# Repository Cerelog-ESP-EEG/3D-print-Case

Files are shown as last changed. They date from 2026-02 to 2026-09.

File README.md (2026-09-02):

# 3D-Printed Case

This repository contains the files and instructions for custom 3D-printed enclosures designed for the **Cerelog ESP-EEG V1, V2 and 16CH devices**.

| Folder | Device | Size | Notes |
| :--- | :--- | :--- | :--- |
| [`case for 16CH/`](case%20for%2016CH/) | 16-channel | 120.30 x 50.67 x 11.65 mm | Snap fit, no screws. Parametric. Floor openings for the two underside DIP switches. |
| [`case for v2/`](case%20for%20v2/) | V2 | 102.60 x 46.55 x 11.35 mm | Snap fit, no screws. Parametric. |
| [`case for v1/`](case%20for%20v1/) | V1 | 113.23 x 53.98 x 15.00 mm | Legacy, hand-modelled. |

The V2 and 16CH cases are generated from a parametric script rather than modelled by hand — change a constant, re-run, get new STLs. Each folder has its own `README.md`, and a `stl/PRINT.md` with everything you need at the printer.

## Preview for v2 and 16CH Cases Below

| V2 | 16CH |
| :---: | :---: |
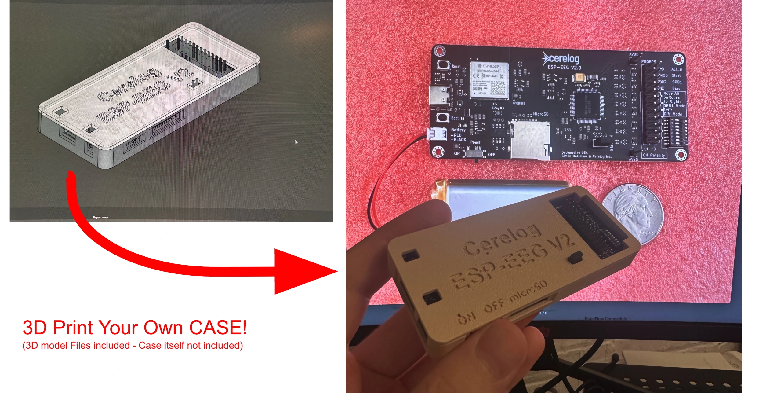
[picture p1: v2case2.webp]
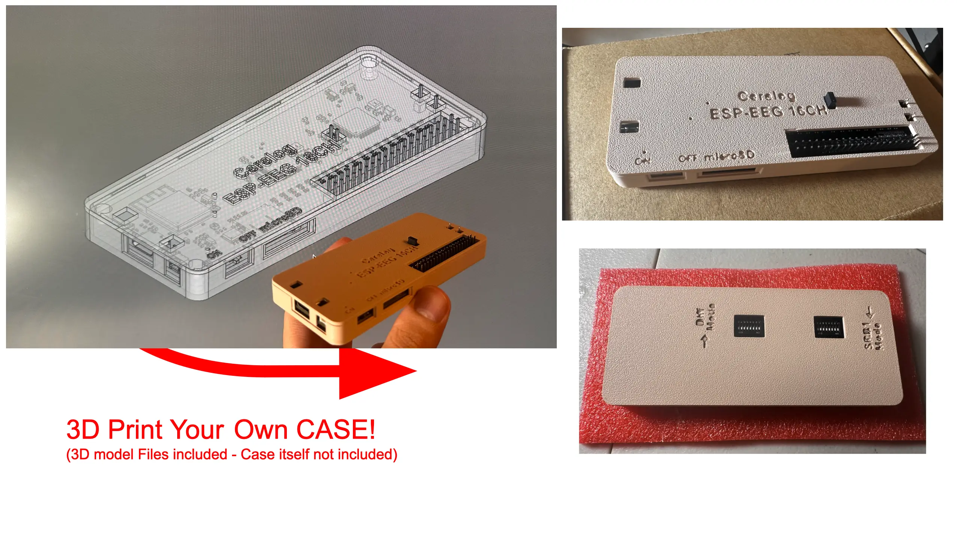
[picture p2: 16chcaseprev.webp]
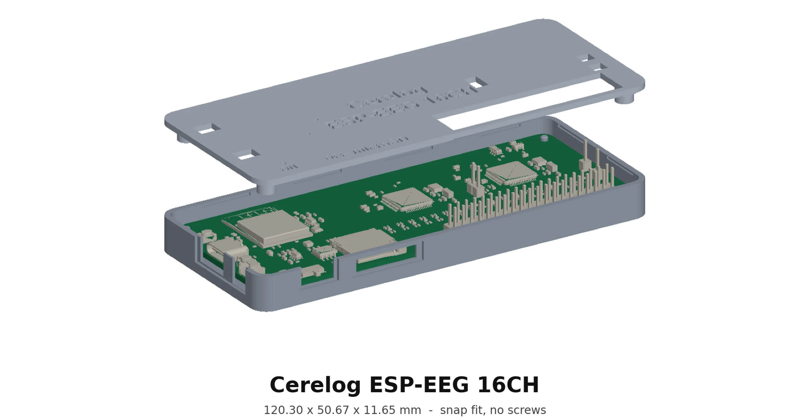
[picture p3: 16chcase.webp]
|  | <br><br> |
| 102.60 x 46.55 x 11.35 mm | 120.30 x 50.67 x 11.65 mm |

## Preview for v1 Case Below

| | | |
| :---: | :---: | :---: |
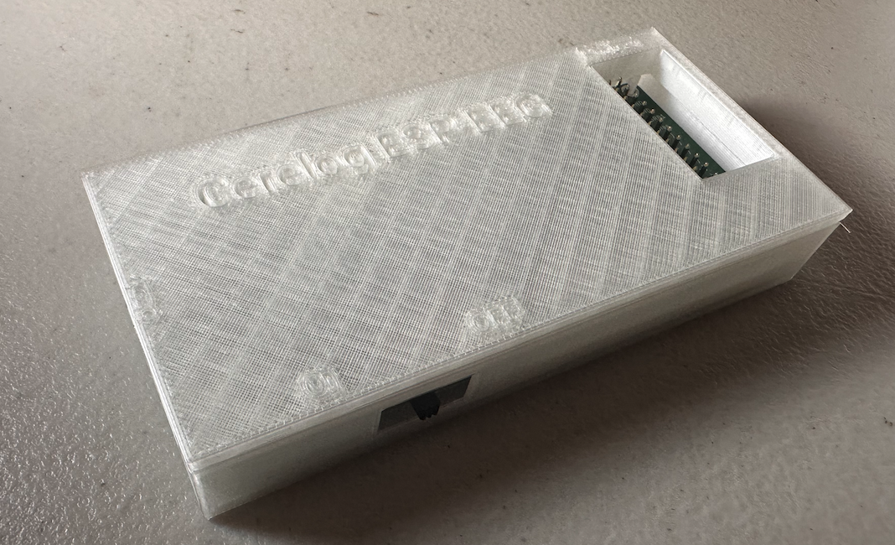
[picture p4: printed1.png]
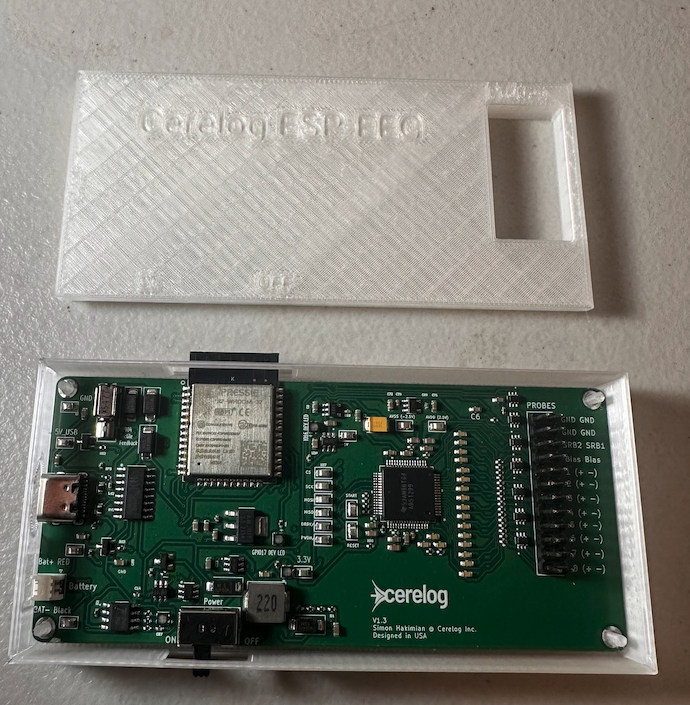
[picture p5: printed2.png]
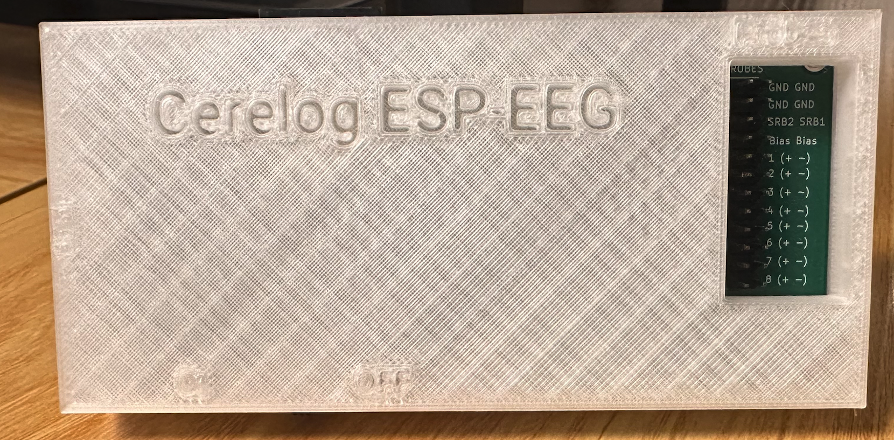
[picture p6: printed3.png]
|  |  |  |
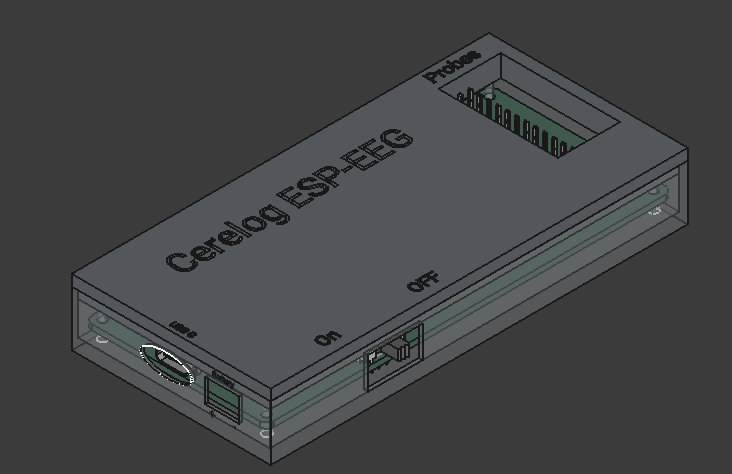
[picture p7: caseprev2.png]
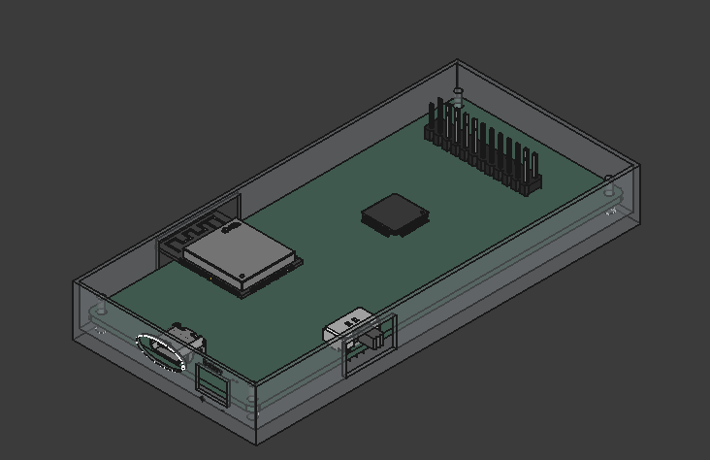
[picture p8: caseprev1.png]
|  |  | |

## Assembly Instructions

1. **Print Files:** Print the two **STL** files included in this repo. 
   > **Note:** The file `Optional_locking_base` is a legacy version with closed ends. You don't need to print it if you plan to tape the lid shut. While the normal lid closes, it can occasionally pop open; the legacy file is designed to prevent the PCB from sliding out.

2. **PCB Installation:**
   * Insert the **antenna** first.
   * Carefully bend the plastic near the **power button** and slot it in while **aligning** the holes with the **PCB**.

3. **Final Step:** Lastly, put the **cover** on.

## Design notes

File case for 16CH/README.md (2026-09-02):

# Cerelog ESP-EEG 16CH — 3D printed case

Snap-fit two-part enclosure, **120.30 x 50.67 x 11.65 mm**. No screws.

**Printing? Go straight to [`stl/PRINT.md`](stl/PRINT.md).**

## Folders

| Folder | What lives there |
|---|---|
| **`stl/`** | The two printable STLs and `PRINT.md`. This is all you need at the printer. |
| **`Case files FreeCAD/`** | FreeCAD documents — the case on its own, the case with the board in it, and the original KiCad STEP export. |
| **`design/`** | The parametric source, measurements, build log, previews, and `tools/`. |

## Seeing the whole assembly in FreeCAD

```sh
/Applications/FreeCAD.app/Contents/MacOS/FreeCAD "design/tools/show_assembly.py"
```

That opens `Case files FreeCAD/assembly_16ch.FCStd` — base, lid and all 220
real board solids in their true positions — with everything made visible, the
lid at 60% transparency and the base at 25% so you can see the fit. A document
built headlessly has no saved GUI state, so opening the file directly will show
most objects hidden; run it through that script the first time.

## How the design is built

The case is **not modelled by hand**. `design/case_16ch.py` builds both parts
from named constants and exports the STLs. Change a number, re-run, get new
parts.

```sh
FC=/Applications/FreeCAD.app/Contents/Resources/bin/freecadcmd
cd design && $FC case_16ch.py
cd tools  && $FC verify_fit.py      # must say PASS
```

`case_16ch.py` writes `design/case_16ch_params.json` on every build. Every tool
reads its dimensions from there, so nothing can drift out of sync with the
model.

## Current design

| | |
|---|---|
| Outer | 120.30 x 50.67 x 11.65 |
| Wall / floor / lid | 1.60 / 1.20 / 1.60 |
| Board mounting | 4 printed pegs, 3.00 mm shoulder, press fit, no screws |
| Lid retention | Snap fit — 9 bead/groove pairs on all four walls, 0.25 mm engagement |
| Lid location | 4 sleeves swallowing the pegs through the board |
| Base openings | USB-C, battery cable, slide switch, microSD, **2 DIP switch holes in the floor** |
| Lid openings | 2x20 electrode header, 1x02 header, 2x 1x01 pins, 2 buttons |
| Markings, lid | `Cerelog` / `ESP-EEG 16CH` engraved 0.80 mm; `ON` `OFF` `microSD` at 0.50 mm |
| Markings, base | DIP switch mode legend: `Diff Mode` (-X side) and `SRB1 Mode` (+X side), 3.40 mm text, rotated 90 deg so the arrows run along the DHA-08TQR travel axis. `Diff` points toward the connector edge, `SRB1` away. 0.50 mm deep, mirrored to read when the case is rolled over |
| LED holes | 3 x 1.20 mm through the lid |

Fit is verified by boolean intersection against all 220 real board solids from
the KiCad STEP — not by eye. Latest result is in `design/verify_fit.txt`.

## What changed from the V2 case

Three things drove the redesign; everything else is carried over.

1. **The electrode header moved to the -Y edge** and grew from 2x12 to 2x20.
   Its body stops 0.06 mm short of the lid rim's inner face, so the lid opening
   has to cut the rim away over 52 mm. Snap segments moved onto all four walls
   to compensate — V2 used the two long walls only.
2. **Two `DHA-08TQR` 8-position DIP switches are now on the underside** of the
   board, hanging 2.385 mm below it. They set the standoff height (`BOSS_H`
   3.00, up from V2's 2.50) and each gets a through-opening in the floor.
3. **The board grew** 98.80 x 42.75 -> 116.50 x 46.87.

Full comparison in [`design/16ch_measurements.md`](design/16ch_measurements.md).

## Open items

See [`design/OPEN_ITEMS.md`](design/OPEN_ITEMS.md). The short version: the DIP
switches are recessed 1.82 mm rather than proud (a hard conflict with header
pin clearance — read item 1 before printing a batch), **ON/OFF may be
reversed**, and the power switch actuator no longer reaches the outside face at
all, so it needs a slider cap.

## Not derivable from the files

Two 3D models in `16ch_step.step` are wrong and are deliberately ignored:
`530480210` (battery connector height) and the unnamed `SOLID` / `SOLID001` /
`SOLID002`. Both confirmed by the board designer on the V2 export; the same
models are present here. If either turns out to be real, case height and floor
need revisiting.

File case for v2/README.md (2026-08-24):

# Cerelog ESP-EEG V2 — 3D printed case

Snap-fit two-part enclosure, **102.60 x 46.55 x 11.35 mm**. No screws.

**Printing? Go straight to [`stl/PRINT.md`](stl/PRINT.md).**

## Folders

| Folder | What lives there |
|---|---|
| **`stl/`** | The two printable STLs and `PRINT.md`. This is all you need at the printer. |
| **`Case files FreeCAD/`** | FreeCAD documents — the case on its own, the case with the board in it, and the original KiCad STEP export. |
| **`design/`** | The parametric source, measurements, build log, previews, and `tools/`. |

## How the design is built

The case is **not modelled by hand**. `design/case_v2.py` builds both parts from
named constants and exports the STLs. Change a number, re-run, get new parts.

```sh
FC=/Applications/FreeCAD.app/Contents/Resources/bin/freecadcmd
cd design && $FC case_v2.py
cd tools  && $FC verify_fit.py      # must say PASS
```

`case_v2.py` writes `design/case_v2_params.json` on every build. Every tool
reads its dimensions from there, so nothing can drift out of sync with the
model.

## Current design

| | |
|---|---|
| Outer | 102.60 x 46.55 x 11.35 |
| Wall / floor / lid | 1.60 / 1.20 / 1.60 |
| Board mounting | 4 printed pegs, 2.50 mm shoulder, press fit, no screws |
| Lid retention | Snap fit — 6 bead/groove pairs, 0.25 mm engagement |
| Lid location | 4 sleeves swallowing the pegs through the board |
| Openings | USB-C, battery cable, slide switch, microSD; lid: header block, 1x02 header, 2 buttons |
| Markings | `Cerelog` / `ESP-EEG V2` engraved 0.80 mm; `ON` `OFF` `microSD` at 0.50 mm |
| LED holes | 3 x 1.20 mm through the lid |

Fit is verified by boolean intersection against all 156 real board solids from
the KiCad STEP — not by eye. Latest result is in `design/verify_fit.txt`.

## Open items

See [`design/OPEN_ITEMS.md`](design/OPEN_ITEMS.md). The short version: **ON/OFF
may be reversed** (no electrical data exists in a STEP file), two LED holes
land inside the engraved title, and the power switch still needs a slider cap
to be usable.

## Not derivable from the files

Two 3D models in `v2_step.step` are wrong and are deliberately ignored:
`530480210` (battery connector height) and the unnamed `SOLID` / `SOLID001` /
`SOLID002`. Both confirmed by the board designer. If either turns out to be
real, case height and floor need revisiting.

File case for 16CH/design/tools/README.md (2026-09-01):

# tools/

Verification and preview scripts for the 16CH case. None of these change the
design — `../case_16ch.py` is the only file that does.

They all read dimensions from `../case_16ch_params.json`, which `case_16ch.py`
rewrites on every build. Nothing hard-codes a Z value.

## The loop

```sh
FC=/Applications/FreeCAD.app/Contents/Resources/bin/freecadcmd

cd ../ && $FC case_16ch.py         # 1. build   -> stl/, Case files FreeCAD/, params
cd tools/
$FC verify_fit.py                 # 2. check   -> ../verify_fit.txt   MUST say PASS
$FC export_board_mesh.py          # 3. meshes for the renderer
python3 render_preview.py         # 4. picture -> ../preview.png
$FC build_assembly.py             # 5. case + board document
/Applications/FreeCAD.app/Contents/MacOS/FreeCAD show_assembly.py   # 6. open it
```

`measure_board.py` is run-once tooling: it produced
`../16ch_raw_measurements.txt`, which `../16ch_measurements.md` is written
from. Re-run it if the board is re-exported.

## What each does

| Script | Runs under | Purpose |
|---|---|---|
| `measure_board.py` | freecadcmd | Extracts board outline, mount holes, every solid's extents, below-board protrusions and edge-proximate parts. |
| `verify_fit.py` | freecadcmd | Every board solid vs base and lid, plus base-vs-lid, peg/sleeve mate, LED holes, DIP switch floor access and port alignment. Writes `../verify_fit.txt`. |
| `export_board_mesh.py` | freecadcmd | Tessellates the board for the renderer. Coarse; pictures only. |
| `render_preview.py` | python3 | Six-view z-buffer render to `../preview.png`. |
| `build_assembly.py` | freecadcmd | Rebuilds `assembly_16ch.FCStd` (case + board). |
| `show_assembly.py` | FreeCAD GUI | Opens it with everything visible, lid translucent. |
| `_paths.py` | — | Shared paths, params loader, bad-model list. |

## Four mistakes baked in as guardrails

**`verify_fit.py` uses a 0.001 mm3 threshold.** On the V2 case it was 0.5, and
that hid a real 0.09 mm3 collision — the check reported a clean fit that was
not clean. Do not raise it.

**`render_preview.py` uses a z-buffer, not depth sorting.** The painter's
algorithm version drew engraved text through the solid lid, which read as the
engraving cutting clean through when it was 0.80 mm into 1.60 mm. Do not
"simplify" it back to sorting triangles.

**`verify_fit.py` also checks port *alignment*, not just interference.** A
no-collision result only proves nothing touches; it does not prove an opening
is actually in front of a connector. The port check sweeps each connector's own
footprint outward through its wall and looks for material in the way.

**`verify_fit.py` measures whether the engraving perforates the lid.** On V2 a
bad preview render made the 0.80 mm engraving look like a through-cut and there
was no measurement to settle it. The check now boxes the lid from the plate
underside up to each engraving floor and reports the void volume — it must be
0.0000 mm3.

## Known-bad models in 16ch_step.step

Confirmed wrong by the board designer on the V2 export; the same models appear
here. Skipped by every check:

- `530480210` — battery connector, height wrong.
- `SOLID`, `SOLID001`, `SOLID002` — unnamed, claim 4.21 mm below the board.

They live in `_paths.BAD_MODELS_*`. If either turns out to be real, the case
height and floor both need revisiting.

`_paths.TOP_LEVEL` additionally drops the STEP's top-level compound
`"16chpcbcad 1"`, which repeats every child shape. Note the sub-parts
`"16chpcbcad 1.211"` ... `"1.216"` are **real** bottom-side solids and are kept.

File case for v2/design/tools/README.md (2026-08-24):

# tools/

Verification and preview scripts for the v2 case. None of these change the
design — `../case_v2.py` is the only file that does.

They all read dimensions from `../case_v2_params.json`, which `case_v2.py`
rewrites on every build. Nothing hard-codes a Z value.

## The loop

```sh
FC=/Applications/FreeCAD.app/Contents/Resources/bin/freecadcmd

cd ../ && $FC case_v2.py          # 1. build   -> stl/, Case files FreeCAD/, params
cd tools/
$FC verify_fit.py                 # 2. check   -> ../verify_fit.txt   MUST say PASS
$FC export_board_mesh.py          # 3. meshes for the renderer
python3 render_preview.py         # 4. picture -> ../preview.png
$FC build_assembly.py             # 5. case + board document
/Applications/FreeCAD.app/Contents/MacOS/FreeCAD show_assembly.py   # 6. open it
```

## What each does

| Script | Runs under | Purpose |
|---|---|---|
| `verify_fit.py` | freecadcmd | Every board solid vs base and lid, plus base-vs-lid, peg/sleeve mate, LED holes. Writes `../verify_fit.txt`. |
| `export_board_mesh.py` | freecadcmd | Tessellates the board for the renderer. Coarse; pictures only. |
| `render_preview.py` | python3 | Six-view z-buffer render to `../preview.png`. |
| `build_assembly.py` | freecadcmd | Rebuilds `assembly_v2.FCStd` (case + board). |
| `show_assembly.py` | FreeCAD GUI | Opens it with everything visible, lid translucent. |
| `_paths.py` | — | Shared paths, params loader, bad-model list. |

## Two mistakes baked in as guardrails

**`verify_fit.py` uses a 0.001 mm3 threshold.** It was 0.5, and that hid a real
0.09 mm3 collision — the check reported a clean fit that was not clean. Do not
raise it.

**`render_preview.py` uses a z-buffer, not depth sorting.** The painter's
algorithm version drew engraved text through the solid lid, which read as the
engraving cutting clean through when it was 0.80 mm into 1.60 mm. Do not
"simplify" it back to sorting triangles.

## Known-bad models in v2_step.step

Confirmed wrong by the board designer, skipped by every check:

- `530480210` — battery connector, height wrong.
- `SOLID`, `SOLID001`, `SOLID002` — unnamed, claim 4.21 mm below the board.

They live in `_paths.BAD_MODELS_*`. If either turns out to be real, the case
height and floor both need revisiting.

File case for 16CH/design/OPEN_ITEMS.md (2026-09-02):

# Open items — 16CH case

Ordered by how much damage each does if ignored.

## 1. DIP switches are recessed 1.82 mm, not proud  — needs a decision

The two `DHA-08TQR` 8-position DIP switches are on the underside of the board
and each has a through-opening in the case floor (12.90 x 9.70 mm, 0.80 mm
clearance all round). They are reachable with a pen tip. They do **not** sit
flush with the outside of the case.

Measured: switch underside sits at case Z **1.82**; the outside of the floor
is Z 0.00.

This is a hard geometric conflict, not an oversight:

```
switch underside   = FLOOR_T + BOSS_H - 2.385
flush with outside => FLOOR_T + BOSS_H = 2.385
with FLOOR_T 1.20  => BOSS_H = 1.185
but the header pins protrude 1.405  => they would hit the floor
```

Making the switches flush requires dropping `BOSS_H` from 3.00 to about 1.60
**and** adding relief pockets under every header pin row. That is the opposite
of "more clearance under the board", so it was not done.

**If you want them proud instead of recessed, say so** — it is `BOSS_H` plus a
`FLOOR_RELIEF` list, both already wired into `case_16ch.py`.

## 2. ON / OFF may be reversed — carried over from V2, still unresolved

`ON` is engraved at X -49.00, `OFF` at X -34.50, flanking the slide-switch
actuator at X -41.96. Those positions come from the actuator's location and
travel axis, which the STEP does give.

What the STEP does **not** give is anything electrical — no netlist, no
reference designators, no schematic. Nothing available here says which throw
of `MK-12C02-G020` actually powers the board.

**Action:** meter a real board, or check the schematic. Same open item as V2;
if it was resolved there, the answer carries over unchanged (same part, same
orientation).

## 3. Power switch still needs a slider cap

The actuator is a 1.30 x 1.16 mm nub. On this board it passes the board edge
by 0.36 mm:

```
actuator past board edge   0.36 mm
minus PCB-to-wall gap      0.30
minus wall (thinned to 0.60)
= it does not reach the outside face at all
```

Worse than V2, which had 1.00 mm of overhang. The 10.10 mm wall opening has
room for the travel, but you cannot work the switch with a fingertip. It needs
a third printed part: a socket that press-fits over the nub with a paddle
reaching out through the opening. **Not built.**

## 4. The -Y lid rim is interrupted over 52 mm

The 2x20 electrode header body stops **0.06 mm** short of the lid rim's inner
face, so the opening for it has to take the rim with it. Over X 0.30..52.30
the lid has no rim — just a 1.735 mm ledge of plate sitting on the 1.60 mm
base wall.

The opening is Y -23.60..-12.40, i.e. **11.20 mm** across a 5.08 mm header
body. It was widened 4.00 mm inboard on purpose, for finger room when seating
ribbon cables; the outer edge stayed at the wall.

Consequences, all accepted deliberately:

- No snap segments are possible on the -Y wall over that span. Retention there
  comes from the +Y wall (4 segments) and the two ends (3 segments). V2 used
  +/-Y only; this case uses all four walls.
- The lid is less stiff along that edge than V2's. If it bows in practice, the
  fix is a rib on the underside inboard of the opening, not a thicker lid.

## 5. Header pin clearance rests on a modelled value

`BOSS_H` 3.00 leaves 1.60 mm below the modelled header pin tips (-1.405) and
0.62 mm below the DIP switches (-2.385). Those are the *models'* values. Two
models in the V2 export already turned out wrong, and clipped through-hole
pins vary a lot with how they are trimmed.

**Action:** caliper a real assembled board before committing to a batch. The
DIP switch height in particular is worth checking — it is now the part that
sets the standoff.

## 6. Both STLs have self-intersecting facet pairs — benign, print them

`case_16ch_lid.stl` is **watertight, manifold, correctly oriented, and its
mesh volume matches the solid exactly** (9140.0 vs 9140.0 mm3) — but carries
24 self-intersecting facet pairs.

All of them sit between Z 10.90 and 11.65, i.e. inside the engraved lettering:
the `ON`/`OFF`/`microSD` label row and the title block. This is FreeCAD's
ShapeString glyph tessellation, not the case geometry — the same defect V2 had,
in the same strings. The count rose from 16 when the title was shrunk from
7.0 mm to 4.5 mm; smaller glyphs tessellate into more slivers. It is the same
benign class of defect either way.

No engraving perforates either part — `verify_fit.py` measures the void under
every engraved string and reports 0.0000 mm3 for all seven. Thinnest remaining
material is 0.80 mm under the lid title (of 1.60 mm) and 0.70 mm under the
bottom mode legend (of 1.20 mm).

**Do not run FreeCAD's mesh repair on it.** On V2 the sequence
`fixSelfIntersections` / `removeFoldsOnSurface` deleted real geometry and
broke solidity.

**Recommendation: print it.** Watertight + manifold + consistent normals is
what slicers actually need. If a slicer refuses, the one-line fallback is to
empty `LABELS` in `case_16ch.py` and rebuild.

`case_16ch_base.stl` carries **22** pairs, all in Z 0.00..0.50 — the band of
the bottom-face mode legend, i.e. the same glyph-tessellation defect. It was
completely clean before that legend was added, and the count dropped from 42
to 22 when the legend text went from 2.60 to 3.40 mm: bigger glyphs tessellate
into fewer slivers. Both parts are watertight, manifold, correctly oriented,
and match their solid volumes (base 11259.1 vs 11259.8, lid 9140.0 vs
9139.9 mm3).

## 7. Side-wall texture — not done, deliberately

Same reasoning as V2: use a **textured PEI build plate**. The lid prints
top-face-down so the bed texture lands on the visible face. Geometric texture
is additionally unsafe on the side walls here — they are locally thinned to
0.60-0.80 mm at the switch, microSD and -X ports.

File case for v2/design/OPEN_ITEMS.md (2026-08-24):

# Open items — v2 case

Ordered by how much damage each does if ignored.

## 1. ON / OFF may be reversed  — BLOCKING a production print

`ON` is engraved at X -38.00, `OFF` at X -27.00, flanking the slide-switch
actuator at X -32.46. Those positions come from the actuator's location and
its travel axis, both of which the STEP does give.

What the STEP does **not** give is anything electrical. There is no netlist, no
reference designator, no schematic. Nothing in any file available here says
which throw of `MK-12C02-G020` actually powers the board.

**Action:** meter a real board, or check the schematic. A case that labels the
power switch backwards is worse than one with no label at all.

## 2. Power switch is not usable — needs a slider cap

The actuator is a **1.30 x 1.16 mm nub** protruding 1.47 mm from the switch
body. It passes the board edge by only 1.00 mm.

```
actuator past board edge   1.00 mm
minus PCB-to-wall gap      0.30
minus wall (already thinned to 0.60)
= protrusion               0.10 mm
```

No wall thickness fixes this. Even at zero wall you would be sliding 0.70 mm of
a 1.3 mm-wide tab with a fingertip.

**Fix:** a third printed part — a socket that press-fits over the nub with a
paddle reaching out through the wall opening, widened to ~5 mm for a finger.
The existing 9.00 mm opening already has room for the travel. Not built yet.

## 3. Two LED holes pierce the engraved title  — cosmetic

| LED | Position | Lands in |
|---|---|---|
| `C2874118` | (-17.65, 2.53) | the `e` of `Cerelog` |
| `C2874116` | (-24.25, -4.07) | `ESP-EEG V2`, near `SP` |
| `C2874117` | (-39.60, -16.63) | clear |

The holes must stay over the LEDs, so the fix is to move the title. Shifting
the block to roughly Y +4.5 .. +20.5 clears both. Left alone because it is a
branding decision.

## 4. Header pin clearance rests on a modelled value

The 2.50 mm standoff leaves 1.09 mm below the modelled header pin tips
(-1.41 mm). That is the *model's* pin length. Two models on this board have
already turned out wrong, and clipped through-hole pins vary a lot with how
they are trimmed.

**Action:** caliper a real assembled board before committing to a batch.

## 5. Side-wall texture — not done, deliberately

A realistic moulded grain needs ~1800 shallow dimples. The boolean did not
complete in two minutes on a bare plate, and FDM cannot resolve a 0.18 mm
dimple anyway.

Use a **textured PEI build plate** instead. The lid prints top-face-down, so
the bed texture lands on the visible face and looks genuinely moulded.

Geometric texture on the side walls is additionally unsafe: they are locally
thinned to 0.60-0.80 mm at the switch, microSD and -X ports.

## 6. Lid STL has self-intersections in the engraved lettering

`case_v2_lid.stl` is **watertight, manifold, correctly oriented, correct
volume** — but carries 34 self-intersecting facet pairs.

All of them sit in the engraved letter walls, spanning 0.40 mm in Z (the
engraving depth). Isolated by testing each string on a bare plate:

| String | Self-intersects |
|---|---|
| `ON`, `OFF`, `Cerelog` | no |
| `microSD`, `ESP-EEG V2` | **yes** |

It is FreeCAD's ShapeString glyph tessellation, not the case geometry:

- Persists at every tessellation tolerance from 0.10 down to 0.01.
- Persists across Arial Bold, Arial, Arial Narrow Bold, Verdana Bold,
  Tahoma Bold and DIN Alternate — no font is clean for all three strings.
- Individual curved glyphs (`m c r o S D`) fail on their own at 3 mm; `i`
  does not. Larger sizes do not fix `microSD`.
- The underlying OCC solid is valid, with correct volume.

**Do not run FreeCAD's mesh repair on it.** The sequence
`fixSelfIntersections` / `removeFoldsOnSurface` drops the lid from
6501 mm3 to 2498 mm3 — it deletes real geometry and breaks solidity.

**Recommendation: print it.** Watertight + manifold + consistent normals are
what slicers actually need; self-intersections in engraved text are the most
common benign STL defect and are auto-repaired on import. If a slicer does
refuse, the one-line fallback is to empty `LABELS` and shorten the title.

`case_v2_base.stl` is completely clean on every check.

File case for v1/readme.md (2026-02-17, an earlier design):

## Assembly Instructions

Note; the file called Optional_locking_base is a legacy file with closed ends and requires the below instructions. You dont need to print it though if you are going to tape the lid shut. Normal lid closes but pops open sometimes and the legacy file can keep pcb from flying out.

1. **Print Files:** Print the two **STL** files included in this repo. 
2. **PCB Installation:** * Insert the **antenna** first.
    * Carefully bend the plastic near the **power button** and slot it in while **aligning** the holes with the **PCB**.
3. **Final Step:** Lastly, put the **cover** on.

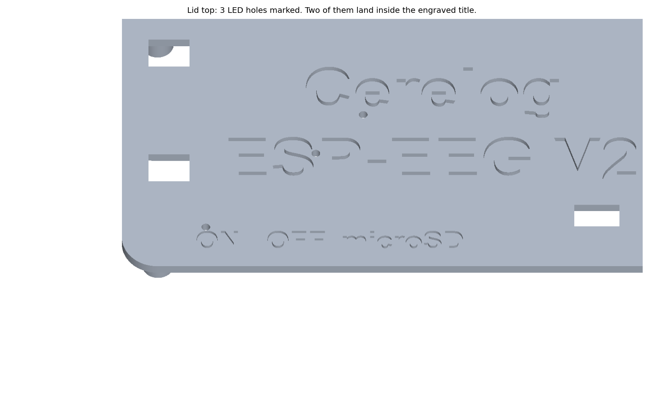
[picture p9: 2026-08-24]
case for v2/design/label_detail.png

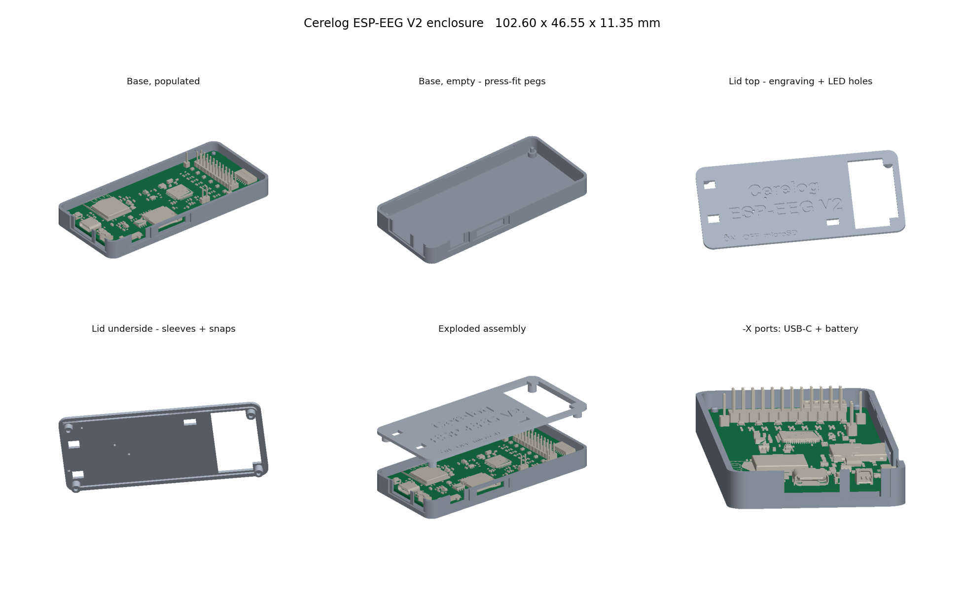
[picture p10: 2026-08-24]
case for v2/design/preview.png

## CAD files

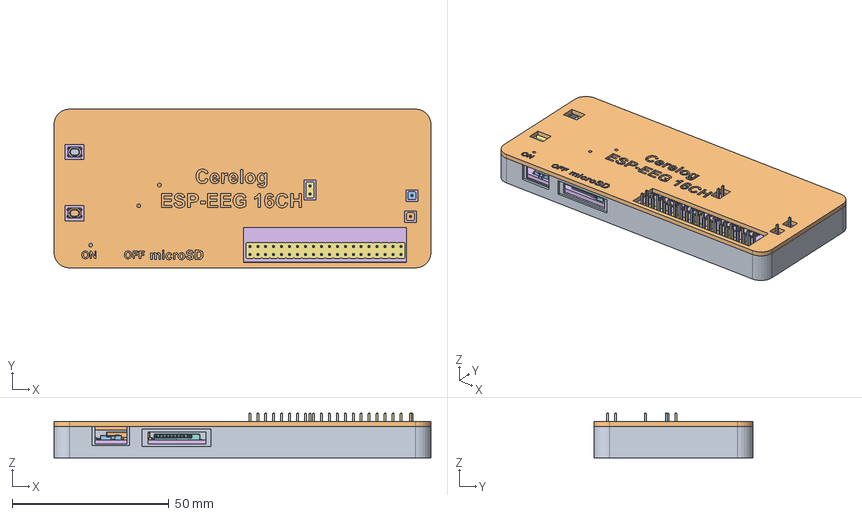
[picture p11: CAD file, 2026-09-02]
case for 16CH/Case files FreeCAD/assembly_16ch.FCStd
120.3 x 50.7 x 14.3 mm
CASE_BASE
CASE_LID
PCB: C_0603_1608Metric
PCB: C_0402_1005Metric
PCB: C_1206_3216Metric
PCB: R_0402_1005Metric
PCB: C_0402_1005Metric001
PCB: R_0402_1005Metric001
PCB: C_0402_1005Metric002
PCB: R_0402_1005Metric002
PCB: R_0402_1005Metric003
PCB: C_0402_1005Metric003
PCB: C_0402_1005Metric004
PCB: R_0402_1005Metric004
PCB: C_0402_1005Metric005
PCB: C_0402_1005Metric006
PCB: C_0402_1005Metric007
PCB: SKRPABE010
PCB: C_0603_1608Metric001
PCB: C_0402_1005Metric008
PCB: C_0402_1005Metric009
PCB: C_0402_1005Metric010
PCB: C_0603_1608Metric002
PCB: R_0402_1005Metric005
PCB: C_0603_1608Metric003
PCB: R_0402_1005Metric006
PCB: R_0402_1005Metric007
PCB: R_0402_1005Metric008
PCB: C_0402_1005Metric011
PCB: C_0402_1005Metric012
PCB: TAJB107K006RNJ
PCB: 530480210
PCB: C_0402_1005Metric013
PCB: R_0402_1005Metric009
PCB: C_0402_1005Metric014
PCB: R_0402_1005Metric010
PCB: C_0603_1608Metric004
PCB: C_0402_1005Metric015
PCB: R_0402_1005Metric011
PCB: C_0402_1005Metric016
PCB: TPS72325DBVR
PCB: C_0402_1005Metric017
PCB: C_0402_1005Metric018
PCB: C_0603_1608Metric005
PCB: C_0603_1608Metric006
PCB: C_0402_1005Metric019
PCB: R_0402_1005Metric012
PCB: TAJB107K006RNJ001
PCB: R_0402_1005Metric013
PCB: C_0402_1005Metric020
PCB: R_0402_1005Metric014
PCB: C_0402_1005Metric021
PCB: C_0402_1005Metric022
PCB: C_0603_1608Metric007
PCB: R_0402_1005Metric015
PCB: C_0402_1005Metric023
PCB: R_0402_1005Metric016
PCB: C_0402_1005Metric024
PCB: C_0603_1608Metric008
PCB: C_0402_1005Metric025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

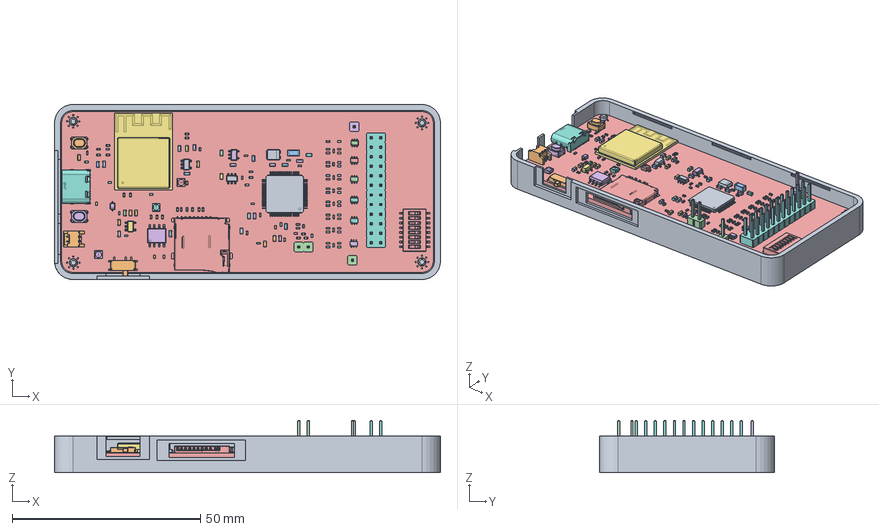
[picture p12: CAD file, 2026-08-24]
case for v2/Case files FreeCAD/assembly_v2.FCStd
102.6 x 46.6 x 13.8 mm
CASE_BASE
PCB: C_0603_1608Metric
PCB: C_1206_3216Metric
PCB: R_0402_1005Metric
PCB: C_0402_1005Metric
PCB: R_0402_1005Metric001
PCB: R_0402_1005Metric002
PCB: R_0402_1005Metric003
PCB: R_0402_1005Metric004
PCB: C_0402_1005Metric001
PCB: C_0402_1005Metric002
PCB: R_0402_1005Metric005
PCB: C_0402_1005Metric003
PCB: SKRPABE010
PCB: C_0603_1608Metric001
PCB: C_0402_1005Metric004
PCB: C_0402_1005Metric005
PCB: C_0402_1005Metric006
PCB: C_0603_1608Metric002
PCB: v2_step 1.19
PCB: R_0402_1005Metric006
PCB: R_0402_1005Metric007
PCB: R_0402_1005Metric008
PCB: C_0402_1005Metric007
PCB: TAJB107K006RNJ
PCB: 530480210
PCB: C_0402_1005Metric008
PCB: C_0402_1005Metric009
PCB: DHA-08TQR
PCB: TPS72325DBVR
PCB: C_0402_1005Metric010
PCB: C_0603_1608Metric003
PCB: C_0603_1608Metric004
PCB: R_0402_1005Metric009
PCB: C_0402_1005Metric011
PCB: C_0402_1005Metric012
PCB: C_0402_1005Metric013
PCB: C_0603_1608Metric005
PCB: R_0402_1005Metric010
PCB: C_0603_1608Metric006
PCB: C_0402_1005Metric014
PCB: C_0603_1608Metric007
PCB: R_0402_1005Metric011
PCB: C_0603_1608Metric008
PCB: C_0402_1005Metric015
PCB: C_0603_1608Metric009
PCB: C_0402_1005Metric016
PCB: C_0402_1005Metric017
PCB: R_0402_1005Metric012
PCB: R_0402_1005Metric013
PCB: C_0603_1608Metric010
PCB: PinHeader_1x01_P2.54mm_Vertical
PCB: R_0402_1005Metric014
PCB: C_0402_1005Metric018
PCB: C_0402_1005Metric019
PCB: PinHeader_2x12_P2.54mm_Vertical
PCB: R_0402_1005Metric015
PCB: C_0402_1005Metric020
PCB: C_0603_1608Metric011
PCB: C_0402_1005Metric021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

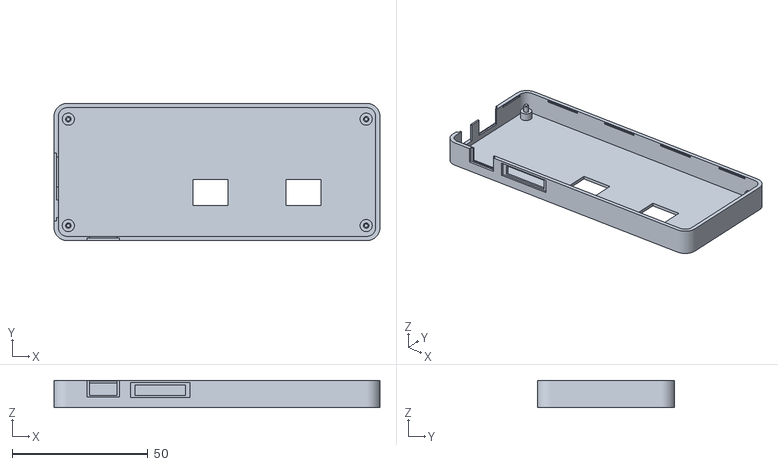
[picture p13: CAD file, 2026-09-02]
case for 16CH/stl/case_16ch_base.stl
120.3 x 50.7 x 10.1

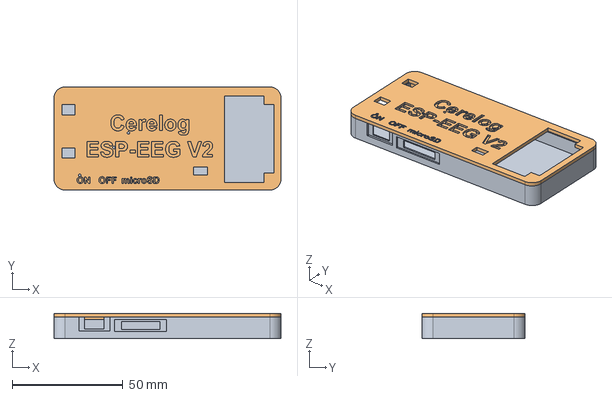
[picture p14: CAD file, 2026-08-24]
case for v2/Case files FreeCAD/case_v2.FCStd
102.6 x 46.6 x 11.3 mm
base
lid

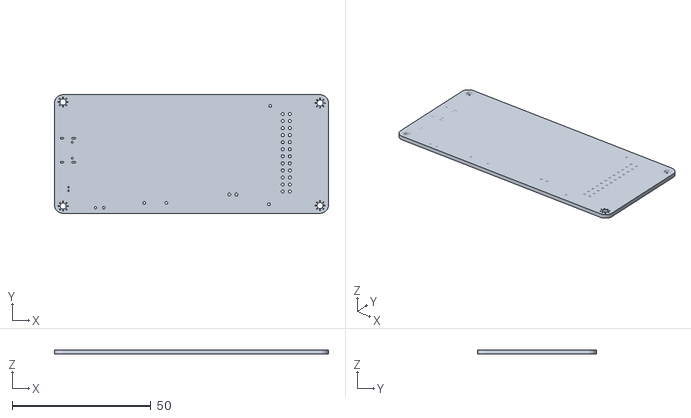
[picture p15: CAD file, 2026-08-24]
case for v2/design/tools/_pv_pcb.stl
98.8 x 42.8 x 1.51

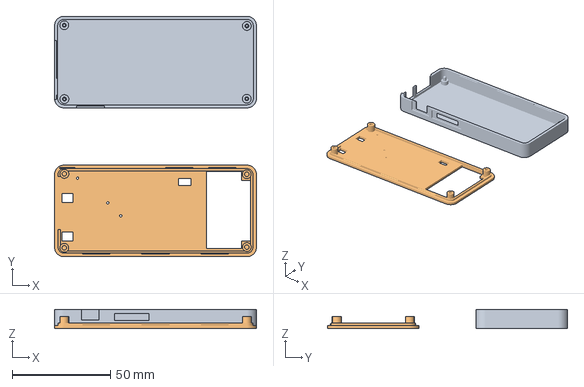
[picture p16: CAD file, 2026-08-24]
case for v2/stl/case_v2_base.3mf
102.6 x 122.1 x 9.75 mm
case_v2_base.stl
case_v2_lid.stl

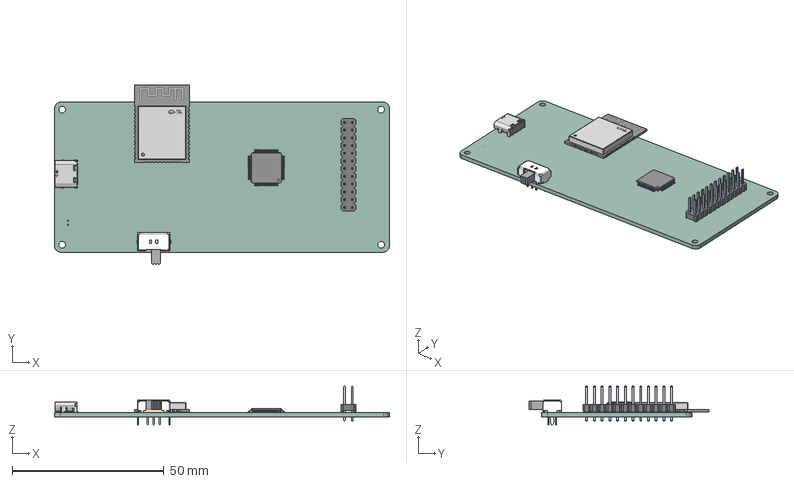
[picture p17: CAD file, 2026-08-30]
v2 FreeCad Design files/model_for_casedev.step
110.3 x 59.1 x 12.7 mm
PZ254V-12-24P
SK22D02L5
ADS1299-6PAG
ESP32-WROOM-32-N4
TYPE-C-16PIN-2MD-073
V6_EEG_1_3_Branch_PCB

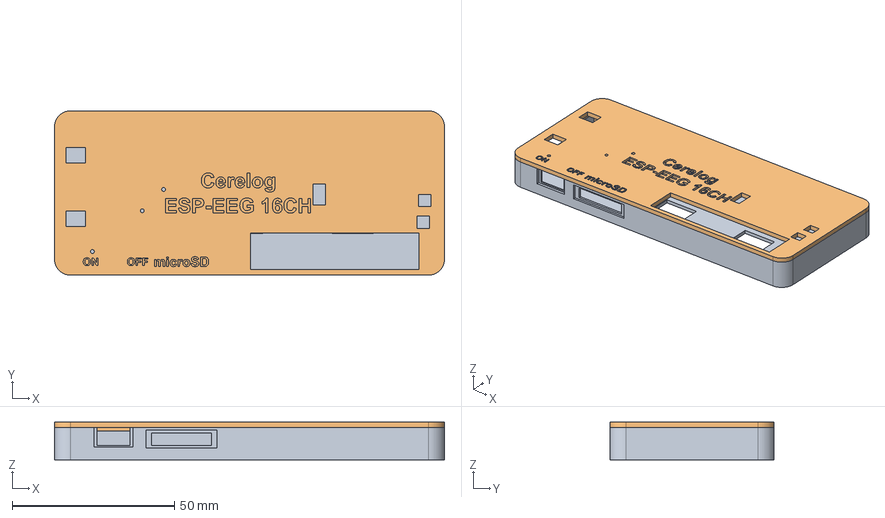
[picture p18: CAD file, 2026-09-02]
case for 16CH/Case files FreeCAD/case_16ch.FCStd
120.3 x 50.7 x 11.7 mm
base
lid

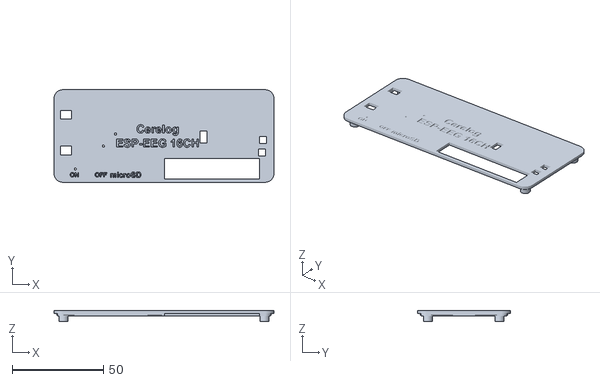
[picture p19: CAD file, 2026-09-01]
case for 16CH/stl/case_16ch_lid.stl
120.3 x 50.7 x 5.84

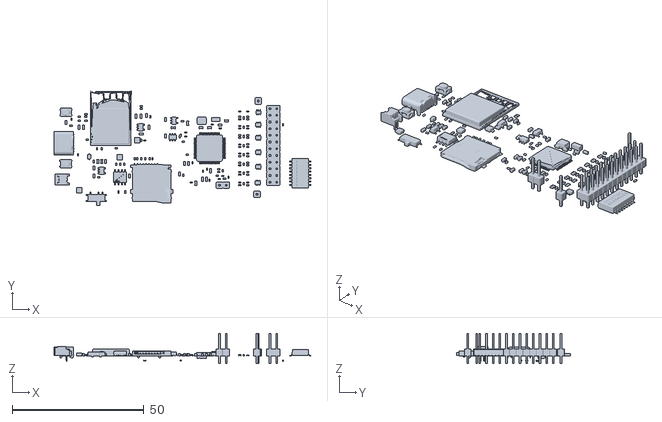
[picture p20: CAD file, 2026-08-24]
case for v2/design/tools/_pv_comp.stl
97.7 x 43.3 x 11.5

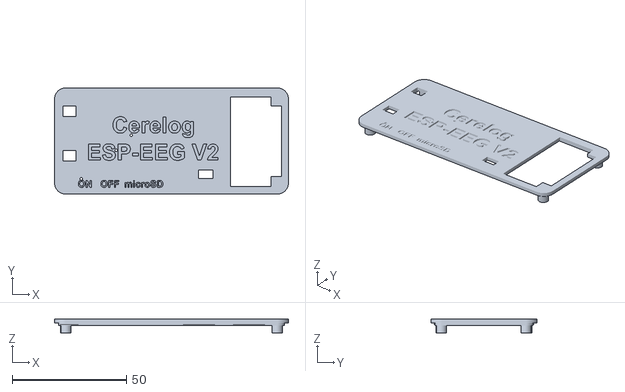
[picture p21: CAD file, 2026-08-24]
case for v2/stl/case_v2_lid.stl
102.6 x 46.5 x 6.04

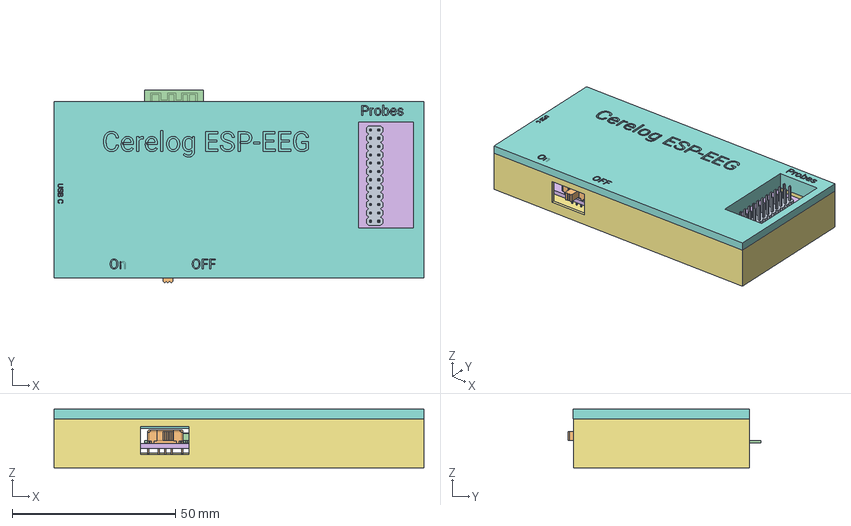
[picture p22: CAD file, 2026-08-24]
v2 FreeCad Design files/Case.FCStd
113.3 x 59.1 x 18.0 mm
PZ254V-12-24P
SK22D02L5
ADS1299-6PAG
ESP32-WROOM-32-N4
TYPE-C-16PIN-2MD-073
V6_EEG_1_3_Branch_PCB
Lid

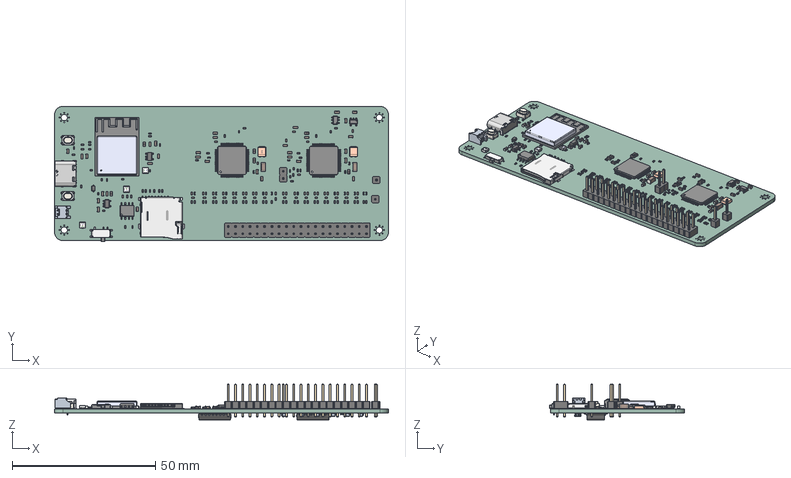
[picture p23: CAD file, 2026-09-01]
case for 16CH/Case files FreeCAD/16ch_step.step
116.5 x 47.2 x 12.5 mm
C_0603_1608Metric x 38
C_0402_1005Metric x 74
C_1206_3216Metric x 2
R_0402_1005Metric x 73
SKRPABE010 x 2
TAJB107K006RNJ x 2
TPS72325DBVR
PinHeader_1x01_P2.54mm_Vertical x 2
SOT-23-5 x 2
D_SOD-323
PinHeader_2x20_P2.54mm_Vertical
C2874116 x 3
ADS1299-6PAG x 2
ESP32-S3-MINI-1-N8
PinHeader_1x02_P2.54mm_Vertical
TF-SMD_TF-01A
TYPE-C-16PIN-2MD-073
TP4056-42-ESOP8
LM2664M6
16chpcbcad 1.211 x 6
DHA-08TQR x 2
V16CH_PCB

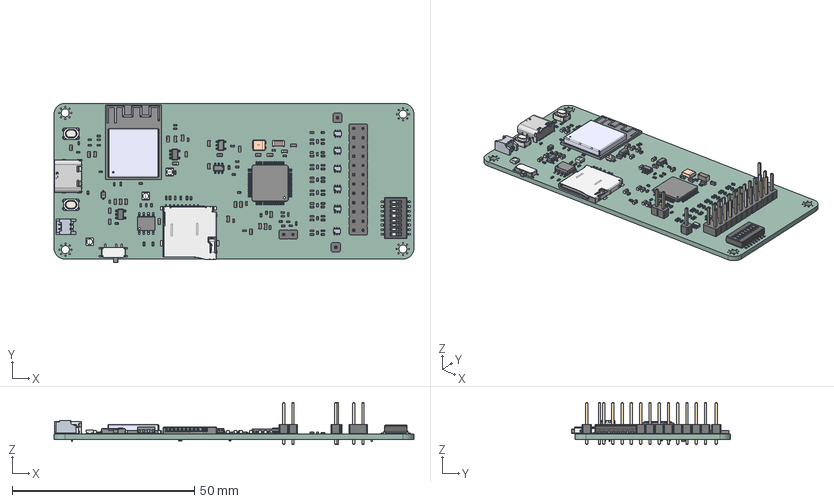
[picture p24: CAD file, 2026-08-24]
case for v2/Case files FreeCAD/v2_step.step
98.8 x 43.7 x 11.5 mm
C_0603_1608Metric x 29
C_1206_3216Metric
R_0402_1005Metric x 53
C_0402_1005Metric x 43
SKRPABE010 x 2
v2_step 1.19 x 6
TAJB107K006RNJ
DHA-08TQR
TPS72325DBVR
PinHeader_1x01_P2.54mm_Vertical x 2
PinHeader_2x12_P2.54mm_Vertical
SOT-23-5 x 2
D_SOD-323
C2874116 x 3
ADS1299-6PAG
ESP32-S3-MINI-1-N8
PinHeader_1x02_P2.54mm_Vertical
TF-SMD_TF-01A
TYPE-C-16PIN-2MD-073
TP4056-42-ESOP8
LM2664M6
2_0_PCB

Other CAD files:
v2 FreeCad Design files/better_base.FCStd
case for v1/case_base_fixed.stl
case for v1/case_lid.stl
case for v1/Optional_locking_base.stl
case for v2/stl/case_v2_base.stl

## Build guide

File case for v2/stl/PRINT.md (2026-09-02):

# What to print — Cerelog ESP-EEG V2 case

## Print these two. Nothing else.

Files here: https://github.com/Cerelog-ESP-EEG/3D-print-Case/tree/main/case%20for%20v2/stl

| File | What it is |
|---|---|
| `case_v2_base.stl` | Bottom half. Walls, floor, 4 press-fit pegs, all port openings. |
| `case_v2_lid.stl`  | Top half. Engraving, LED holes, snap beads, 4 sleeves. |

Assembled size **102.60 x 46.55 x 11.35 mm**. No screws, no hardware.

## Orientation — read this before slicing

**Base:** floor flat on the bed, walls up. This is how it exports. No supports.

**Lid: FLIP IT 180 degrees.** The STL exports with the rim and sleeves pointing
*down* (STL spans Z 5.31..11.35). If you drop it straight onto the bed the
slicer balances it on four sleeves and prints the plate in mid-air.

Rotate 180 degrees about X so the **engraved top face lies on the bed** and the
rim and sleeves build upward. Then there are no overhangs anywhere and no
supports are needed.

Bonus: a **textured PEI sheet** puts a moulded-grain finish on the lid top,
which is the face you look at. That is the intended finish — the texture is
deliberately not in the geometry.

## Settings

- Nozzle 0.4, layer 0.2. Nothing here needs finer.
- **No supports on either part.**
- Walls are 1.60 mm (4 perimeters). Locally 0.60-0.80 mm at the switch,
  microSD and -X ports — do not let the slicer gap-fill those away.
- Two bridges in the base, over the microSD opening (17.4 mm) and the switch
  opening (9.0 mm). Slow that layer down.
- 3-4 perimeters, 20-30% infill. Material is not critical; PETG or ABS if the
  snap needs to survive repeated opening, PLA is fine otherwise.

## Assembly

1. Drop the PCB straight down onto the four pegs in the base. It seats on the
   2.50 mm shoulders; the pegs pass through the 2.20 mm mounting holes.
   **No flexing or bending is needed** — unlike the v1 case. The slide switch
   overhangs the board edge by 0.695 mm, so its slot is cut open all the way
   to the top of the wall to let the board drop in vertically. Verified by
   sweeping every protruding part down its insertion path against the base.
2. Press the lid on. The four sleeves swallow the protruding pegs, and three
   snap beads per long wall click into grooves in the base wall.
3. To open: pull from a short end. The snaps are 0.25 mm engagement, split
   into 14 mm segments so they release without tools.

## Before you print a second one

Three things are unresolved and would change the parts:

- **ON / OFF may be backwards.** The labels are placed from the switch
  actuator's position and travel axis. The STEP carries no electrical data, so
  nothing told me which throw actually powers the board. Meter it.
- **Two LED holes pierce the engraved title** (in `Cerelog` and `ESP-EEG V2`).
  Works fine, looks like damage. Fix is to move the title, not the holes.
- **The power switch actuator is a 1.30 x 1.16 mm nub** and sits roughly flush
  with the wall. No wall thickness fixes this; it needs a printed slider cap,
  which does not exist yet.

## Known-bad data in v2_step.step

Two 3D models in the KiCad export are wrong and were deliberately ignored:

- `530480210` battery connector — height is wrong.
- `SOLID`, `SOLID001`, `SOLID002` — unnamed, claim to hang 4.21 mm below the
  board. Confirmed not real.

If either turns out to be genuine, the case height and floor need revisiting.

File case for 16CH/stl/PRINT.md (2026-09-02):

# What to print — Cerelog ESP-EEG 16CH case

## Print these two. Nothing else.

Files: Here: https://github.com/Cerelog-ESP-EEG/3D-print-Case/tree/main/case%20for%2016CH/stl 

| File | What it is |
|---|---|
| `case_16ch_base.stl` | Bottom half. Walls, floor, 4 press-fit pegs, all port openings, 2 DIP switch holes, mode legend on the outside face. |
| `case_16ch_lid.stl`  | Top half. Engraving, LED holes, snap beads, 4 sleeves. |

Assembled size **120.30 x 50.67 x 11.65 mm**. No screws, no hardware.

## Orientation — read this before slicing

**Base:** floor flat on the bed, walls up. This is how it exports. No supports.

**Lid: FLIP IT 180 degrees.** The STL exports with the rim and sleeves pointing
*down* (STL spans Z 5.81..11.65). If you drop it straight onto the bed the
slicer balances it on four sleeves and prints the plate in mid-air.

Rotate 180 degrees about X so the **engraved top face lies on the bed** and the
rim and sleeves build upward. Then there are no overhangs anywhere and no
supports are needed.

Bonus: a **textured PEI sheet** puts a moulded-grain finish on the lid top,
which is the face you look at. That is the intended finish — the texture is
deliberately not in the geometry.

## Settings

- Nozzle 0.4, layer 0.2. Nothing here needs finer.
- **No supports on either part.**
- Walls are 1.60 mm (4 perimeters). Locally 0.60-0.80 mm at the switch,
  microSD and -X ports — do not let the slicer gap-fill those away.
- Bridges in the base: the microSD opening (18.5 mm) and the two DIP switch
  floor holes (12.90 mm each, but these are in the first layers over open air
  below — they are plain holes, nothing to bridge). Slow the microSD layer down.
- The switch opening is cut open to the top of the wall, so it needs no bridge.
- 3-4 perimeters, 20-30% infill. Material is not critical; PETG or ABS if the
  snap needs to survive repeated opening, PLA is fine otherwise.
- The base is 120.30 mm long — check it fits your plate in the orientation you
  want. It does not fit diagonally on a 120 mm bed with a brim.

## Assembly

1. Drop the PCB straight down onto the four pegs in the base. It seats on the
   3.00 mm shoulders; the pegs pass through the 2.20 mm mounting holes.
   The slide switch overhangs the board edge by 0.36 mm, so its slot is cut
   open all the way to the top of the wall to let the board drop in vertically.
2. Check the two DIP switches drop into their floor openings without touching.
   There is 0.80 mm of clearance on every side.
3. Press the lid on. The four sleeves swallow the protruding pegs, and nine
   snap beads — 4 on +Y, 2 on -Y, 2 on +X, 1 on -X — click into grooves in the
   base wall. The -Y wall carries only two because the electrode header opening
   removes the rim over 52 mm of it.
4. To open: pull from a short end. The snaps are 0.25 mm engagement, split into
   6-14 mm segments so they release without tools.

## The DIP switches

Both `DHA-08TQR` 8-position switches face **downward, out through the base**.
Their openings are 12.90 x 9.70 mm.

The outside of the base is engraved either side of the openings, 0.50 mm deep
into the 1.20 mm floor:

```
   connector edge (electrode header / power switch / microSD)
   ------------------------------------------------------------
                                                  |
     D M                                          v
     i o      [ SW1 ]          [ SW2 ]           S M
     f d                                         R o
     f e                                         B d
      ^                                          1 e
      |
```

Both legends are **rotated 90 deg**, so the arrows run along the axis the
DHA-08TQR actuators actually travel (8 actuators in a row along the long axis,
each sliding across it). `Diff Mode` is on the -X side, `SRB1 Mode` on the +X
side.

With the case rolled over, **`Diff Mode` points toward the connector edge** —
the edge carrying the electrode header, power switch and microSD — and
**`SRB1 Mode` points toward the opposite edge**. These were reversed on the
first print; flip them again by swapping the two signs in `BOT_GROUPS`.

Text is **3.40 mm**. It was 2.60 on the first print, where Arial Bold strokes
come out ~0.45 mm — about one 0.4 mm extrusion, which prints mushy. At 3.40
the strokes are ~0.59 mm. V2's panel labels are 3.00 for comparison.

The legend is **mirrored**, so it reads correctly when you roll the case over
about its long axis — the way you would naturally turn a 120 mm case to reach
the switches. `SRB1 Mode` is then on your right. Each group is 6.9 mm clear of
its opening.

The switch bodies sit **1.82 mm inside** the opening — they are not flush with
the outside of the case. Set them with a pen tip or a small screwdriver. This
is a geometric consequence of keeping 1.60 mm of clearance under the header
pins; see `../design/OPEN_ITEMS.md` item 1 for the exact trade and the
one-constant change if you want them proud instead.

## Before you print a second one

- **ON / OFF may be backwards.** The labels come from the switch actuator's
  position and travel axis. The STEP carries no electrical data. Meter it.
- **The power switch actuator does not reach the outside face** — it passes the
  board edge by only 0.36 mm, less than V2's 1.00 mm. It needs a printed slider
  cap, which does not exist yet.
- **Caliper the DIP switch height** on a real board. At 2.385 mm modelled, it is
  now the part that sets the standoff height.

## Known-bad data in 16ch_step.step

The same wrong models as the V2 export, deliberately ignored:

- `530480210` battery connector — height is wrong.
- `SOLID`, `SOLID001`, `SOLID002` — unnamed, claim to hang 4.21 mm below the
  board. Confirmed not real.

If either turns out to be genuine, the case height and floor need revisiting.

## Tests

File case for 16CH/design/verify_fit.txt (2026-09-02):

case  120.30 x 50.67 x 11.65    PCB underside at Z 4.20
skipping known-bad models: 530480210 (height wrong), SOLID, SOLID001, SOLID002

=== BOARD vs CASE (intersection > 0.001 mm3) ===
  none  (220 solids checked)

=== BASE vs LID ===
  0.0000 mm3  clean

=== peg / sleeve mate ===
  peg top 6.91, sleeve mouth 5.81 -> engagement 1.10 mm
  peg ( -54.86, -19.77)  obstruction 0.0000 mm3  clear
  peg (  55.05, -19.77)  obstruction 0.0000 mm3  clear
  peg ( -54.86,  19.50)  obstruction 0.0000 mm3  clear
  peg (  55.05,  19.50)  obstruction 0.0000 mm3  clear

=== LED holes clear through the lid ===
  LED ( -26.50,   1.10)  obstruction 0.0000 mm3  open
  LED ( -48.45, -18.05)  obstruction 0.0000 mm3  open
  LED ( -33.10,  -5.50)  obstruction 0.0000 mm3  open

=== DIP switch access through the floor ===
  DHA-08TQR      footprint 11.29 x  8.10  floor obstruction   0.0000 mm3  open
  DHA-08TQR001   footprint 11.29 x  8.10  floor obstruction   0.0000 mm3  open
  switch underside sits at Z 1.82; floor outer face is Z 0.00
  -> recessed 1.82 mm inside the opening (operate with a pen tip)

=== port alignment (connector footprint swept out through its wall) ===
  TYPE-C-16PIN-2MD-073   -X  USB-C                obstruction    0.000 mm3  clear
  530480210              -X  battery / PicoBlade  obstruction    0.000 mm3  clear
  MK-12C02-G020          -Y  power slide switch   obstruction    0.000 mm3  clear
  TF-SMD_TF-01A          -Y  microSD socket       obstruction    0.000 mm3  clear

=== engraving vs lid thickness (does the text cut through?) ===
  'Cerelog'    0.80 deep of 1.60 -> 0.80 mm must remain, Z 10.05..10.85
               void under it   0.0000 mm3  solid
  'ESP-EEG 16CH' 0.80 deep of 1.60 -> 0.80 mm must remain, Z 10.05..10.85
               void under it   0.0000 mm3  solid
  'ON'         0.50 deep of 1.60 -> 1.10 mm must remain, Z 10.05..11.15
               void under it   0.0000 mm3  solid
  'OFF'        0.50 deep of 1.60 -> 1.10 mm must remain, Z 10.05..11.15
               void under it   0.0000 mm3  solid
  'microSD'    0.50 deep of 1.60 -> 1.10 mm must remain, Z 10.05..11.15
               void under it   0.0000 mm3  solid
  thinnest point of the lid anywhere under an engraving: 0.80 mm

=== bottom-face engraving vs floor thickness ===
  'Diff Mode >'  0.50 deep of 1.20 -> 0.70 mm must remain, Z 0.50..1.20
                 void under it   0.0000 mm3  solid
                 8.03 mm of floor between it and dip_switch_1
  'SRB1 Mode <'  0.50 deep of 1.20 -> 0.70 mm must remain, Z 0.50..1.20
                 void under it   0.0000 mm3  solid
                 8.00 mm of floor between it and dip_switch_2

=== printability spot-checks ===
  wall 1.60, thinned to 0.60 (switch) / 0.80 (microSD) / 0.70 (-X ports)
  lid ledge over the -Y wall where the header opening removes the rim:
      1.735 mm of lid plate on a 1.60 mm wall

RESULT: PASS

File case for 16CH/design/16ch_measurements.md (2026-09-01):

# 16CH PCB — measured geometry

Source: `Case files FreeCAD/16ch_step.step` (KiCad STEP export, 224 solids).
All values in mm, extracted via FreeCAD headless by `tools/measure_board.py`;
raw output in `16ch_raw_measurements.txt`. Board origin is at the PCB center.

## Board

| Property | Value |
|---|---|
| Outline | 116.50 x 46.87 (rounded rect) |
| Extents | X -58.25..58.25, Y -23.43..23.43 |
| Thickness | 1.51 |
| Corner radius | 3.00 (4 arcs + 4 lines, clean outline) |
| Top face area | 5391.6 mm2 |

## Mounting holes — D = 2.20 (M2 clearance)

| # | X | Y |
|---|---|---|
| 1 | -54.859 | -19.766 |
| 2 |  55.050 | -19.766 |
| 3 | -54.859 |  19.501 |
| 4 |  55.050 |  19.501 |

NOTE: not symmetric. X spread is 0.19, Y spread 0.265. Standoffs use these
exact coordinates, not a mirrored pattern.

## Vertical envelope

| | Z |
|---|---|
| Highest point (pin headers) | +10.135 |
| PCB top | +1.510 |
| PCB bottom | 0.000 |
| Lowest real point (DHA-08TQR DIP switches) | -2.385 |
| Lowest modelled point (unidentified SOLID, bogus) | -4.206 |
| Total real stack | 12.52 |

## Below-board protrusions (these drive standoff height)

| Part | Z min | Footprint |
|---|---|---|
| **DHA-08TQR** (DIP switch) | **-2.385** | X -8.00..3.30, Y -11.62..-3.52 |
| **DHA-08TQR001** (DIP switch) | **-2.385** | X 26.21..37.50, Y -11.62..-3.52 |
| PinHeader 2x20 | -1.405 | X 1.06..51.86 |
| PinHeader 1x02 / 1x01 x2 | -1.405 | various |
| unnamed solids `16chpcbcad 1.211..216` | -1.185 | X 20.8..49.7, Y -14.95..-12.72 |
| 530480210 battery conn | -0.611 | X -58.13..-52.62 |
| C_0402 (one bottom-side cap) | -0.585 | X 41.43..42.43 |
| SOLID (UNIDENTIFIED, bogus) | -4.206 | X -2.12..2.12, Y -4.53..0.98 |

The two DHA-08TQR are 8-position DIP switches mounted on the **underside** of
the board. They set `BOSS_H` and each gets a through-opening in the case floor.

## Components requiring wall openings

| Part | Function | Edge | Overhang | Z range |
|---|---|---|---|---|
| TYPE-C-16PIN-2MD-073 | USB-C | -X | 0.15 inside | 0.77..4.93 |
| 530480210 | battery (PicoBlade) | -X | 0.13 inside | -0.61..5.20 |
| MK-12C02-G020 | slide switch | -Y | 0.36 PAST edge | 1.10..3.00 |
| TF-SMD_TF-01A | microSD | -Y | 0.56 inside | 0.85..3.43 |

## Components requiring top access

| Part | Function | Position | Z top |
|---|---|---|---|
| PinHeader 2x20 | electrode header | X 1.06..51.86, Y -22.28..-17.20 | 10.135 |
| PinHeader 1x02 | | X 20.28..22.82, Y -3.04..2.04 | 10.135 |
| PinHeader 1x01 x2 | | X 52.38..55.29, Y -10.24..-1.03 | 10.135 |
| SKRPABE010 | tactile button | X -55.93..-51.23, Y -9.65..-6.12 | 4.095 |
| SKRPABE011 | tactile button | X -55.90..-51.20, Y 9.85..13.38 | 4.095 |

## Components requiring bottom access

| Part | Function | Position | Z range |
|---|---|---|---|
| DHA-08TQR | 8-pos DIP switch | X -8.00..3.30, Y -11.62..-3.52 | -2.385..-0.085 |
| DHA-08TQR001 | 8-pos DIP switch | X 26.21..37.50, Y -11.62..-3.52 | -2.385..-0.085 |

## LEDs (lid light-pipe holes)

Same three LCSC parts as V2, 2.10 x 2.11, tops at Z 2.595.

| Part | Centre |
|---|---|
| C2874118 | (-26.505, 1.100) |
| C2874117 | (-48.450, -18.055) |
| C2874116 | (-33.100, -5.495) |

## Change vs V2

- Board grew: 98.80 x 42.75 -> **116.50 x 46.87** (+17.70 x +4.12)
- ADC: **two** ADS1299-6PAG (was one) -> 16 channels
- Electrode header moved from the **+X edge** to the **-Y edge**, and grew
  from 2x12 to **2x20**. This is the single biggest case change: the lid
  opening for it has to cut through the -Y lid rim over 52 mm.
- **Two DHA-08TQR moved to the underside of the board.** On V2 the single
  DHA-08TQR was top-side at the +X edge with a wall opening. They are now
  8-position DIP switches under the board and need floor openings.
- MCU, charger, LDO, charge pump, microSD, buttons, slide switch, battery
  connector, LEDs: all unchanged from V2.
- Case grew: 102.60 x 46.55 x 11.35 -> 120.30 x 50.67 x 11.65

## No copper exported

224 solids: board outline + component bodies only. No netlist, no reference
designators, no gerbers. Same as the V2 export — which is why ON/OFF polarity
still cannot be derived from this file.

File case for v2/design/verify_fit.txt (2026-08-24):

case  102.60 x 46.55 x 11.35    PCB underside at Z 3.70
skipping known-bad models: 530480210 (height wrong), SOLID, SOLID001, SOLID002

=== BOARD vs CASE (intersection > 0.001 mm3) ===
  none  (156 solids checked)

=== BASE vs LID ===
  0.1616 mm3  CLASH

=== peg / sleeve mate ===
  peg top 6.41, sleeve mouth 5.31 -> engagement 1.10 mm
  peg ( -46.27, -18.79)  obstruction 0.0000 mm3  clear
  peg (  46.37, -18.61)  obstruction 0.0000 mm3  clear
  peg ( -46.33,  18.75)  obstruction 0.0000 mm3  clear
  peg (  46.40,  18.38)  obstruction 0.0000 mm3  clear

=== LED holes clear through the lid ===
  LED ( -24.25,  -4.07)  obstruction 0.0000 mm3  open
  LED ( -39.60, -16.63)  obstruction 0.0000 mm3  open
  LED ( -17.65,   2.53)  obstruction 0.0000 mm3  open

RESULT: PASS

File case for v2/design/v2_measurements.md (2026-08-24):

# v2 PCB — measured geometry

Source: `v2_step.step` (KiCad STEP export, 236 solids). All values in mm,
extracted via FreeCAD headless. Board origin is at the PCB center.

## Board

| Property | Value |
|---|---|
| Outline | 98.80 x 42.75 (rounded rect) |
| Extents | X -49.40..49.40, Y -21.38..21.38 |
| Thickness | 1.51 |
| Corner radius | 3.00 (4 arcs + 4 lines, clean outline) |
| Top face area | 4163.8 mm2 |

## Mounting holes — D = 2.20 (M2 clearance)

| # | X | Y |
|---|---|---|
| 1 | -46.27 | -18.79 |
| 2 |  46.37 | -18.61 |
| 3 | -46.33 |  18.75 |
| 4 |  46.40 |  18.38 |

NOTE: not symmetric. Spread is 0.13 in X and 0.41 in Y. Standoffs must use
these exact coordinates, not a mirrored pattern.

## Vertical envelope

| | Z |
|---|---|
| Highest point (pin headers) | +10.14 |
| PCB top | +1.51 |
| PCB bottom | 0.00 |
| Lowest point (unidentified SOLID) | -4.21 |
| Total stack | 14.35 |

## Below-board protrusions (drive standoff height)

| Part | Z min | Footprint |
|---|---|---|
| SOLID (UNIDENTIFIED) | -4.21 | X -2.12..2.12, Y -4.53..0.98 |
| PinHeader 2x12 | -1.41 | X 31.60..36.68 |
| PinHeader 1x01 / 1x02 | -1.41 | various |
| 530480210 battery conn | -0.61 | X -48.88..-43.38 |

## Components requiring wall openings

| Part | Function | Edge | Overhang | Z range |
|---|---|---|---|---|
| TYPE-C-16PIN-2MD-073 | USB-C | -X | 0.15 inside | 0.77..4.93 |
| 530480210 | battery (PicoBlade) | -X | 0.52 inside | -0.61..5.20 |
| MK-12C02-G020 | slide switch | -Y | 0.99 PAST edge | 1.09..3.00 |
| TF-SMD_TF-01A | microSD | -Y | 0.08 PAST edge | 0.85..3.43 |
| DHA-08TQR | connector | +X | 0.95 inside | 1.60..3.90 |
| ESP32-S3-MINI-1-N8 | module (RF keepout) | +Y | 0.40 inside | 2.39..4.15 |

## Components requiring top access

| Part | Function | Position | Z top |
|---|---|---|---|
| SKRPABE010 | tactile button | X -47.08..-42.38, Y -8.23..-4.69 | 4.09 |
| SKRPABE011 | tactile button | X -47.05..-42.35, Y 11.27..14.81 | 4.09 |
| PinHeader 2x12 | electrode header | X 31.60..36.68, Y -14.76..15.72 | 10.14 |
| PinHeader 1x01 x2 | X 26.63..29.67 | +/-Y edge area | 10.14 |
| PinHeader 1x02 | X 12.39..17.47, Y -15.89..-13.35 | | 10.14 |

## Change vs v1

- MCU: ESP32-WROOM-32-N4 -> ESP32-S3-MINI-1-N8
- ADC: ADS1299-6PAG (unchanged)
- NEW: TP4056 charger + LM2664 charge pump + TPS72325 LDO -> battery powered
- NEW: TF-SMD_TF-01A microSD socket
- NEW: 2x SKRPABE010 tactile buttons
- NEW: 530480210 Molex PicoBlade battery connector
- Switch changed: SK22D02L5 -> MK-12C02-G020
- Board shrank: v1 case was 113.23 x 53.98 x 15.00

## No copper exported

Entity census found zero copper layer assignments, no track/via/zone naming,
236 solids. Board outline + component bodies only. No netlist, no gerbers.

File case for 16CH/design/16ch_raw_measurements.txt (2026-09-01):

total objects with solids: 224
GLOBAL bbox  X -58.250..58.250  Y -23.794..23.434  Z -4.206..10.135
GLOBAL size  116.500 x 47.229 x 14.341

=== candidates for the PCB substrate (thin, large footprint) ===
  V16CH_PCB                            5460.2 mm2  116.50 x 46.87 x 1.51  Z 0.000..1.510

PCB  = V16CH_PCB
PCB  outline 116.500 x 46.869  thickness 1.510
PCB  X -58.250..58.250  Y -23.434..23.434  Z 0.000..1.510
PCB  centre (0.000, -0.000)

=== PCB top face analysis ===
top face area 5391.6 mm2, wires 93
outline: 8 edges (4 arcs, 4 lines)
outline arc radii: [3.0]

=== holes in the PCB (inner wires of the top face) ===
inner wires: 92
   D  2.200  at (  55.050,   19.501)   edges 1
   D  2.200  at (  55.050,  -19.766)   edges 1
   D  2.200  at ( -54.859,   19.501)   edges 1
   D  2.200  at ( -54.859,  -19.766)   edges 1
   D  1.500  at ( -51.301,   -4.368)   edges 4
   D  1.500  at ( -51.301,    4.272)   edges 4
   D  1.200  at ( -55.511,    4.272)   edges 4
   D  1.200  at ( -55.511,   -4.368)   edges 4
   D  1.100  at (  21.550,    0.804)   edges 1
   D  1.100  at (  21.550,   -1.736)   edges 1
   D  1.000  at (  54.018,   -2.297)   edges 1
   D  1.000  at (  53.650,   -8.966)   edges 1
   D  1.000  at (  50.590,  -18.466)   edges 1
   D  1.000  at (  50.590,  -21.006)   edges 1
   D  1.000  at (  48.050,  -18.466)   edges 1
   D  1.000  at (  48.050,  -21.006)   edges 1
   D  1.000  at (  45.510,  -18.466)   edges 1
   D  1.000  at (  45.510,  -21.006)   edges 1
   D  1.000  at (  42.970,  -18.466)   edges 1
   D  1.000  at (  42.970,  -21.006)   edges 1
   D  1.000  at (  40.430,  -18.466)   edges 1
   D  1.000  at (  40.430,  -21.006)   edges 1
   D  1.000  at (  37.890,  -18.466)   edges 1
   D  1.000  at (  37.890,  -21.006)   edges 1
   D  1.000  at (  35.350,  -18.466)   edges 1
   D  1.000  at (  35.350,  -21.006)   edges 1
   D  1.000  at (  32.810,  -18.466)   edges 1
   D  1.000  at (  32.810,  -21.006)   edges 1
   D  1.000  at (  30.270,  -18.466)   edges 1
   D  1.000  at (  30.270,  -21.006)   edges 1
   D  1.000  at (  27.730,  -18.466)   edges 1
   D  1.000  at (  27.730,  -21.006)   edges 1
   D  1.000  at (  25.190,  -18.466)   edges 1
   D  1.000  at (  25.190,  -21.006)   edges 1
   D  1.000  at (  22.650,  -18.466)   edges 1
   D  1.000  at (  22.650,  -21.006)   edges 1
   D  1.000  at (  20.110,  -18.466)   edges 1
   D  1.000  at (  20.110,  -21.006)   edges 1
   D  1.000  at (  17.570,  -18.466)   edges 1
   D  1.000  at (  17.570,  -21.006)   edges 1

=== mounting-hole sized (D 1.8 .. 4.5) ===
   D  2.200  at ( -54.859,  -19.766)
   D  2.200  at (  55.050,  -19.766)
   D  2.200  at ( -54.859,   19.501)
   D  2.200  at (  55.050,   19.501)

=== ALL SOLIDS (excluding the PCB), by top Z ===
label                                    Zmin     Zmax   X range            Y range           
PinHeader_2x20_P2.54mm_Vertical        -1.405   10.135      1.06..  51.86   -22.28.. -17.20
16chpcbcad 1                           -2.385   10.135    -58.25..  58.25   -23.79..  23.43
PinHeader_1x02_P2.54mm_Vertical        -1.405   10.135     20.28..  22.82    -3.04..   2.04
PinHeader_1x01_P2.54mm_Vertical001     -1.405   10.135     52.38..  54.92   -10.24..  -7.70
PinHeader_1x01_P2.54mm_Vertical        -1.405   10.135     52.75..  55.29    -3.57..  -1.03
530480210                              -0.611    5.195    -58.13.. -52.62   -15.67.. -11.42
TYPE-C-16PIN-2MD-073                    0.765    4.926    -58.10.. -50.52    -4.52..   4.42
ESP32-S3-MINI-1-N8                      1.595    4.147    -44.15.. -28.75    -0.95..  19.55
SKRPABE011                              1.585    4.095    -55.90.. -51.20     9.85..  13.38
SKRPABE010                              1.585    4.095    -55.93.. -51.23    -9.65..  -6.12
TF-SMD_TF-01A                           0.848    3.433    -29.00.. -12.90   -22.88..  -7.88
TP4056-42-ESOP8                         1.595    3.345    -35.40.. -30.50   -16.05.. -10.05
C_1206_3216Metric001                    1.595    3.195     13.80..  15.40     0.64..   3.84
C_1206_3216Metric                       1.595    3.195     45.74..  47.34     0.63..   3.83
SOT-23-5                                1.595    3.145    -26.49.. -23.69     4.45..   7.35
SOT-23-006                              1.595    3.145    -41.35.. -38.55   -12.00..  -9.10
TPS72325DBVR                            1.595    3.045     44.60..  47.50    16.63..  19.43
LM2664M6                                1.595    3.045     38.34..  41.14    17.14..  20.04
MK-12C02-G020                           1.095    2.995    -45.86.. -38.06   -23.79.. -18.69
ADS1299-6PAG001                         1.595    2.795     -2.32..   9.68    -1.44..  10.56
ADS1299-6PAG                            1.595    2.795     29.63..  41.63    -1.46..  10.54
D_SOD-323                               1.595    2.705    -45.33.. -44.08    -6.46..  -3.96
C2874118                                1.595    2.595    -27.56.. -25.45     0.05..   2.15
C2874117                                1.595    2.595    -49.50.. -47.40   -19.11.. -17.00
C2874116                                1.595    2.595    -34.15.. -32.05    -6.55..  -4.44
TAJB107K006RNJ001                       0.546    2.545     12.70..  15.50     5.70..   9.40
TAJB107K006RNJ                          0.546    2.545     44.65..  47.45     5.68..   9.38
C_0603_1608Metric037                    1.595    2.395    -41.85.. -41.05    -7.85..  -6.25
C_0603_1608Metric036                    1.595    2.395     26.21..  27.81     3.83..   4.63
C_0603_1608Metric035                    1.595    2.395    -43.35.. -42.55   -10.35..  -8.75
C_0603_1608Metric034                    1.595    2.395    -43.35.. -42.55   -13.35.. -11.75
C_0603_1608Metric033                    1.595    2.395     42.98..  43.78     6.96..   8.56
C_0603_1608Metric032                    1.595    2.395    -54.00.. -53.20     6.95..   8.55
C_0603_1608Metric031                    1.595    2.395     42.98..  43.78     3.72..   5.32
C_0603_1608Metric030                    1.595    2.395    -40.35.. -39.55    -7.85..  -6.25
C_0603_1608Metric029                    1.595    2.395    -47.35.. -46.55     5.15..   6.75
C_0603_1608Metric028                    1.595    2.395    -38.85.. -38.05    -7.85..  -6.25
C_0603_1608Metric027                    1.595    2.395     28.97..  30.57    12.13..  12.93
C_0603_1608Metric026                    1.595    2.395    -25.75.. -24.15     3.05..   3.85
C_0603_1608Metric025                    1.595    2.395     11.03..  11.83     3.74..   5.34
C_0603_1608Metric024                    1.595    2.395     11.03..  11.83     6.97..   8.57
C_0603_1608Metric023                    1.595    2.395    -25.35.. -24.55     9.38..  10.98
C_0603_1608Metric022                    1.595    2.395    -27.35.. -26.55     9.38..  10.98
C_0603_1608Metric021                    1.595    2.395     43.98..  44.78    -0.26..   1.34
C_0603_1608Metric020                    1.595    2.395     23.02..  24.62     6.85..   7.65
C_0603_1608Metric019                    1.595    2.395     -2.97..  -1.37    12.15..  12.95
C_0603_1608Metric018                    1.595    2.395     -8.99..  -7.39     5.37..   6.17
C_0603_1608Metric017                    1.595    2.395    -23.35.. -22.55     9.65..  11.25
C_0603_1608Metric016                    1.595    2.395     -2.97..  -1.37    13.65..  14.45
C_0603_1608Metric015                    1.595    2.395     -8.92..  -7.32     6.87..   7.67
C_0603_1608Metric014                    1.595    2.395    -49.05.. -48.25     5.12..   6.72
C_0603_1608Metric013                    1.595    2.395     -5.73..  -4.13     3.84..   4.64
C_0603_1608Metric012                    1.595    2.395     44.25..  45.85    12.45..  13.25
C_0603_1608Metric011                    1.595    2.395     42.96..  43.76    17.54..  19.14
C_0603_1608Metric010                    1.595    2.395     45.73..  47.33    20.94..  21.74
C_0603_1608Metric009                    1.595    2.395    -22.35.. -21.55     5.15..   6.75
C_0603_1608Metric008                    1.595    2.395     45.61..  46.41    -2.71..  -1.11
C_0603_1608Metric007                    1.595    2.395     22.96..  24.56     5.35..   6.15
C_0603_1608Metric006                    1.595    2.395     25.00..  26.60    15.63..  16.43
C_0603_1608Metric005                    1.595    2.395     28.97..  30.57    13.63..  14.43
C_0603_1608Metric004                    1.595    2.395     13.66..  14.46    -2.69..  -1.09
C_0603_1608Metric003                    1.595    2.395     12.03..  12.83    -0.24..   1.36
C_0603_1608Metric002                    1.595    2.395    -29.78.. -28.98   -13.32.. -11.72
C_0603_1608Metric001                    1.595    2.395     39.48..  41.07    20.94..  21.74
C_0603_1608Metric                       1.595    2.395     21.50..  23.10     9.38..  10.18
C_0402_1005Metric072                    1.595    2.095     -2.90..  -1.90    -8.72..  -8.22
C_0402_1005Metric071                    1.595    2.095     50.30..  50.80    -7.47..  -6.47
C_0402_1005Metric070                    1.595    2.095     -5.65..  -5.15    -7.45..  -6.45
C_0402_1005Metric069                    1.595    2.095      3.83..   4.33    -7.45..  -6.45
C_0402_1005Metric068                    1.595    2.095      7.60..   8.60    -8.72..  -8.22
C_0402_1005Metric067                    1.595    2.095      4.08..   5.08    -8.70..  -8.20
C_0402_1005Metric066                    1.595    2.095     26.55..  27.55    -0.72..  -0.22
C_0402_1005Metric065                    1.595    2.095     45.55..  46.05    14.34..  15.34
C_0402_1005Metric064                    1.595    2.095     42.80..  43.30    -7.47..  -6.47
C_0402_1005Metric063                    1.595    2.095      0.35..   0.85    -7.47..  -6.47
C_0402_1005Metric062                    1.595    2.095     21.30..  21.80    -7.47..  -6.47
C_0402_1005Metric061                    1.595    2.095     -6.65..  -6.15    -7.45..  -6.45
C_0402_1005Metric060                    1.595    2.095      8.35..   8.85    -7.47..  -6.47
C_0402_1005Metric059                    1.595    2.095     -9.65..  -9.15    -7.45..  -6.45
C_0402_1005Metric058                    1.595    2.095     29.57..  30.57    10.78..  11.28
C_0402_1005Metric057                    1.595    2.095     14.60..  15.60    -8.72..  -8.22
C_0402_1005Metric056                    1.595    2.095     29.05..  30.05    -8.74..  -8.24
C_0402_1005Metric055                    1.595    2.095     43.80..  44.30    -7.45..  -6.45
C_0402_1005Metric054                    1.595    2.095     36.78..  37.28    -7.47..  -6.47
C_0402_1005Metric053                    1.595    2.095     46.55..  47.55    -8.74..  -8.24
C_0402_1005Metric052                    1.595    2.095     32.55..  33.55    -8.74..  -8.24
C_0402_1005Metric051                    1.595    2.095     33.30..  33.80    -7.49..  -6.49
C_0402_1005Metric050                    1.595    2.095      0.60..   1.60    -8.72..  -8.22
C_0402_1005Metric049                    1.595    2.095     39.55..  40.55    -8.74..  -8.24
C_0402_1005Metric048                    1.595    2.095     10.85..  11.35    -7.45..  -6.45
C_0402_1005Metric047                    1.595    2.095      7.35..   7.85    -7.47..  -6.47
C_0402_1005Metric046                    1.595    2.095     12.43..  12.93     3.06..   4.06
C_0402_1005Metric045                    1.595    2.095    -25.20.. -24.70    -6.55..  -5.55
C_0402_1005Metric044                    1.595    2.095     26.30..  26.80     0.53..   1.53
C_0402_1005Metric043                    1.595    2.095    -46.47.. -45.47     9.70..  10.20
C_0402_1005Metric042                    1.595    2.095     22.30..  22.80    11.03..  12.03
C_0402_1005Metric041                    1.595    2.095     22.30..  22.80    -7.47..  -6.47
C_0402_1005Metric040                    1.595    2.095     -4.90..  -3.90     5.30..   5.80
C_0402_1005Metric039                    1.595    2.095     44.38..  44.88     3.04..   4.04
C_0402_1005Metric038                    1.595    2.095     35.78..  36.28    -7.47..  -6.47
C_0402_1005Metric037                    1.595    2.095     27.05..  28.05     5.28..   5.78
C_0402_1005Metric036                    1.595    2.095     11.10..  12.10    -8.68..  -8.18
C_0402_1005Metric035                    1.595    2.095     11.85..  12.35    -7.43..  -6.43
C_0402_1005Metric034                    1.595    2.095     49.30..  49.80    -7.47..  -6.47
C_0402_1005Metric033                    1.595    2.095     -2.15..  -1.65    -7.47..  -6.47
C_0402_1005Metric032                    1.595    2.095     22.96..  23.96     4.30..   4.80
C_0402_1005Metric031                    1.595    2.095    -43.20.. -42.70    -7.55..  -6.55
C_0402_1005Metric030                    1.595    2.095     14.35..  14.85    -7.47..  -6.47
C_0402_1005Metric029                    1.595    2.095    -10.65.. -10.15    -7.45..  -6.45
C_0402_1005Metric028                    1.595    2.095     36.03..  37.03    -8.72..  -8.22
C_0402_1005Metric027                    1.595    2.095     29.80..  30.30    -7.49..  -6.49
C_0402_1005Metric026                    1.595    2.095     46.30..  46.80    -7.49..  -6.49
C_0402_1005Metric025                    1.595    2.095    -21.70.. -21.20     9.45..  10.45
C_0402_1005Metric024                    1.595    2.095     15.35..  15.85    -7.47..  -6.47
C_0402_1005Metric023                    1.595    2.095     -2.38..  -1.38    10.80..  11.30
C_0402_1005Metric022                    1.595    2.095    -34.70.. -34.20    -8.55..  -7.55
C_0402_1005Metric021                    1.595    2.095     25.30..  25.80    -7.47..  -6.47
C_0402_1005Metric020                    1.595    2.095     26.30..  26.80    -7.47..  -6.47
C_0402_1005Metric019                    1.595    2.095    -10.40..  -9.40    -8.70..  -8.20
C_0402_1005Metric018                    1.595    2.095     25.55..  26.55    -8.72..  -8.22
C_0402_1005Metric017                    1.595    2.095      1.35..   1.85    -7.47..  -6.47
C_0402_1005Metric016                    1.595    2.095     10.93..  11.43     0.06..   1.06
C_0402_1005Metric015                    1.595    2.095     24.80..  25.80    14.28..  14.78
C_0402_1005Metric014                    1.595    2.095     40.30..  40.80    -7.49..  -6.49
C_0402_1005Metric013                    1.595    2.095     -3.15..  -2.65    -7.47..  -6.47
C_0402_1005Metric012                    1.595    2.095     21.55..  22.55    -8.72..  -8.22
C_0402_1005Metric011                    1.595    2.095     -8.99..  -7.99     4.32..   4.82
C_0402_1005Metric010                    1.595    2.095     43.05..  44.05    -8.70..  -8.20
C_0402_1005Metric009                    1.595    2.095     28.80..  29.30    -7.49..  -6.49
C_0402_1005Metric008                    1.595    2.095     47.30..  47.80    -7.49..  -6.49
C_0402_1005Metric007                    1.595    2.095     -6.40..  -5.40    -8.70..  -8.20
C_0402_1005Metric006                    1.595    2.095     27.30..  27.80     0.51..   1.51
C_0402_1005Metric005                    1.595    2.095     17.35..  17.85    -7.45..  -6.45
C_0402_1005Metric004                    1.595    2.095     32.30..  32.80    -7.49..  -6.49
C_0402_1005Metric003                    1.595    2.095     42.88..  43.38     0.04..   1.04
C_0402_1005Metric002                    1.595    2.095     18.70..  19.20    -7.47..  -6.47
C_0402_1005Metric001                    1.595    2.095     39.30..  39.80    -7.49..  -6.49
C_0402_1005Metric                       1.595    2.095      4.83..   5.33    -7.45..  -6.45
R_0402_1005Metric072                    1.595    1.945     -6.65..  -6.15   -10.46..  -9.46
R_0402_1005Metric071                    1.595    1.945     -5.15..  -4.15     6.78..   7.28
R_0402_1005Metric070                    1.595    1.945     22.30..  22.80   -10.48..  -9.48
R_0402_1005Metric069                    1.595    1.945     11.85..  12.35   -10.44..  -9.44
R_0402_1005Metric068                    1.595    1.945     15.35..  15.85   -10.44..  -9.44
R_0402_1005Metric067                    1.595    1.945     35.80..  36.30   -10.48..  -9.48
R_0402_1005Metric066                    1.595    1.945     23.69..  24.19    -1.62..  -0.62
R_0402_1005Metric065                    1.595    1.945    -10.65.. -10.15   -10.45..  -9.45
R_0402_1005Metric064                    1.595    1.945     18.70..  19.20    -9.37..  -8.37
R_0402_1005Metric063                    1.595    1.945    -45.95.. -44.95     0.90..   1.40
R_0402_1005Metric062                    1.595    1.945    -48.96.. -47.96     8.20..   8.70
R_0402_1005Metric061                    1.595    1.945    -21.99.. -21.49    -6.55..  -5.55
R_0402_1005Metric060                    1.595    1.945     39.45..  40.45    15.58..  16.08
R_0402_1005Metric059                    1.595    1.945     42.80..  43.30   -10.48..  -9.48
R_0402_1005Metric058                    1.595    1.945    -25.20.. -24.70     0.46..   1.46
R_0402_1005Metric057                    1.595    1.945     14.35..  14.85   -10.45..  -9.45
R_0402_1005Metric056                    1.595    1.945      7.50..   8.50    15.60..  16.10
R_0402_1005Metric055                    1.595    1.945     17.35..  17.85   -10.45..  -9.45
R_0402_1005Metric054                    1.595    1.945     33.30..  33.80   -10.48..  -9.48
R_0402_1005Metric053                    1.595    1.945     26.30..  27.30     6.78..   7.28
R_0402_1005Metric052                    1.595    1.945    -48.96.. -47.96     9.70..  10.20
R_0402_1005Metric051                    1.595    1.945      0.35..   0.85   -10.46..  -9.46
R_0402_1005Metric050                    1.595    1.945    -25.46.. -24.46    12.70..  13.20
R_0402_1005Metric049                    1.595    1.945    -40.19.. -39.69    -2.71..  -1.71
R_0402_1005Metric048                    1.595    1.945     36.80..  37.30   -10.48..  -9.48
R_0402_1005Metric047                    1.595    1.945     43.80..  44.30   -10.46..  -9.46
R_0402_1005Metric046                    1.595    1.945    -46.45.. -45.45     8.20..   8.70
R_0402_1005Metric045                    1.595    1.945    -34.96.. -33.96    -2.30..  -1.80
R_0402_1005Metric044                    1.595    1.945     46.30..  46.80   -10.47..  -9.47
R_0402_1005Metric043                    1.595    1.945      8.35..   8.85   -10.46..  -9.46
R_0402_1005Metric042                    1.595    1.945     25.30..  25.80   -10.48..  -9.48
R_0402_1005Metric041                    1.595    1.945    -25.45.. -24.45    13.70..  14.20
R_0402_1005Metric040                    1.595    1.945     21.30..  21.80   -10.47..  -9.47
R_0402_1005Metric039                    1.595    1.945    -33.80.. -33.30   -19.15.. -18.15
R_0402_1005Metric038                    1.595    1.945    -33.20.. -32.70    -8.55..  -7.55
R_0402_1005Metric037                    1.595    1.945     24.88..  25.38     1.14..   2.14
R_0402_1005Metric036                    1.595    1.945     50.30..  50.80   -10.47..  -9.47
R_0402_1005Metric035                    1.595    1.945     49.30..  49.80   -10.47..  -9.47
R_0402_1005Metric034                    1.595    1.945     39.30..  39.80   -10.48..  -9.48
R_0402_1005Metric033                    1.595    1.945     24.05..  25.05    -2.92..  -2.42
R_0402_1005Metric032                    1.595    1.945      7.35..   7.85   -10.46..  -9.46
R_0402_1005Metric031                    1.595    1.945     37.80..  38.30    14.03..  15.03
R_0402_1005Metric030                    1.595    1.945     29.80..  30.30   -10.48..  -9.48
R_0402_1005Metric029                    1.595    1.945     47.30..  47.80   -10.46..  -9.46
R_0402_1005Metric028                    1.595    1.945     24.80..  25.30    -0.97..   0.03
R_0402_1005Metric027                    1.595    1.945     32.80..  33.30    12.52..  13.52
R_0402_1005Metric026                    1.595    1.945    -20.89.. -20.39    -6.57..  -5.57
R_0402_1005Metric025                    1.595    1.945     10.85..  11.35   -10.46..  -9.46
R_0402_1005Metric024                    1.595    1.945    -42.00.. -41.50    -2.67..  -1.67
R_0402_1005Metric023                    1.595    1.945     40.30..  40.80   -10.48..  -9.48
R_0402_1005Metric022                    1.595    1.945     -9.65..  -9.15   -10.46..  -9.46
R_0402_1005Metric021                    1.595    1.945    -31.30.. -30.80   -19.15.. -18.15
R_0402_1005Metric020                    1.595    1.945     23.65..  24.15     0.40..   1.40
R_0402_1005Metric019                    1.595    1.945    -51.70.. -51.20     8.45..   9.45
R_0402_1005Metric018                    1.595    1.945      3.85..   4.35   -10.46..  -9.46
R_0402_1005Metric017                    1.595    1.945    -27.70.. -27.20    -6.55..  -5.55
R_0402_1005Metric016                    1.595    1.945     -3.15..  -2.65   -10.45..  -9.45
R_0402_1005Metric015                    1.595    1.945    -31.70.. -31.20    -8.55..  -7.55
R_0402_1005Metric014                    1.595    1.945     -5.65..  -5.15   -10.46..  -9.46
R_0402_1005Metric013                    1.595    1.945    -26.70.. -26.20    -6.55..  -5.55
R_0402_1005Metric012                    1.595    1.945      1.35..   1.85   -10.46..  -9.46
R_0402_1005Metric011                    1.595    1.945      5.85..   6.35    14.05..  15.05
R_0402_1005Metric010                    1.595    1.945     -2.15..  -1.65   -10.46..  -9.46
R_0402_1005Metric009                    1.595    1.945      0.85..   1.35    12.54..  13.54
R_0402_1005Metric008                    1.595    1.945     28.80..  29.30   -10.47..  -9.47
R_0402_1005Metric007                    1.595    1.945     32.30..  32.80   -10.48..  -9.48
R_0402_1005Metric006                    1.595    1.945    -23.70.. -23.20    -6.55..  -5.55
R_0402_1005Metric005                    1.595    1.945      4.85..   5.35   -10.46..  -9.46
R_0402_1005Metric004                    1.595    1.945    -46.45.. -45.45    10.70..  11.20
R_0402_1005Metric003                    1.595    1.945    -52.11.. -51.11     6.28..   6.78
R_0402_1005Metric002                    1.595    1.945    -49.20.. -48.70    -5.06..  -4.06
R_0402_1005Metric001                    1.595    1.945     26.30..  26.80   -10.48..  -9.48
R_0402_1005Metric                       1.595    1.945    -41.57.. -40.57   -13.30.. -12.80
SOLID                                  -4.206    1.600     -2.12..   2.12    -4.53..   0.98
SOLID002                                0.000    1.400     -3.90..   3.90    -1.38..   1.38
SOLID001                               -0.500    1.400     -3.30..   3.30    -2.85..   2.25
16chpcbcad 1.216                       -1.185   -0.085     32.42..  34.52   -14.80.. -12.80
16chpcbcad 1.215                       -1.185   -0.085     42.92..  45.02   -14.80.. -12.80
16chpcbcad 1.214                       -1.185   -0.085     26.92..  29.02   -14.80.. -12.80
16chpcbcad 1.213                       -1.185   -0.085     47.56..  49.66   -14.72.. -12.72
16chpcbcad 1.212                       -1.185   -0.085     20.82..  22.92   -14.95.. -12.95
16chpcbcad 1.211                       -1.185   -0.085     37.92..  40.02   -14.80.. -12.80
C_0402_1005Metric073                   -0.585   -0.085     41.43..  42.43   -22.42.. -21.92
DHA-08TQR001                           -2.385   -0.085     26.20..  37.50   -11.62..  -3.52
DHA-08TQR                              -2.385   -0.085     -8.00..   3.30   -11.62..  -3.52
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

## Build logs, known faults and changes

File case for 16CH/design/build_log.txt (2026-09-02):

=== Cerelog ESP-EEG 16CH case ===
outer     120.30 x 50.67 x 10.05 (base+lid = 11.65)
cavity    117.10 x 47.47, corner R 3.30
PCB sits at Z 4.20 .. 5.71
DIP switch underside at Z 1.82 (floor outer face is Z 0.00)
base shell volume 11941.6
after 4 peg standoffs (boss 3.00 + peg 2.71), volume 12165.1
  floor cut dip_switch_1  12.90 x 9.70 mm, removed 150.2 mm3
  floor cut dip_switch_2  12.90 x 9.70 mm, removed 150.2 mm3
  cut usb_c          on -X wall, removed 119.9 mm3
  cut battery_cable  on -X wall, removed 74.4 mm3
  cut slide_switch   on -Y wall, removed 89.7 mm3
  cut microsd        on -Y wall, removed 115.4 mm3
  cut 9 snap grooves, 0.55 mm deep into the 1.60 mm wall
  thin switch_thin   on -Y wall to 0.60 mm, removed 16.5 mm3
  thin microsd_thin  on -Y wall to 0.80 mm, removed 39.1 mm3
  thin minus_x_ports on -X wall to 0.70 mm, removed 53.9 mm3
  bottom 'Diff Mode' X -24.85..-16.83  Y -17.40..2.27  (0.50 deep, 0.70 left under it), removed 20.7 mm3
  bottom 'SRB1 Mode' X 46.30..54.37  Y -17.40..2.27  (0.50 deep, 0.70 left under it), removed 24.4 mm3
  base after bottom engraving: valid=True solids=1
lid blank volume 10178.6
  4 lid sleeves: 4.24 tall, bore 2.30 x 1.70 deep, stop 0.10 above PCB
  3 LED holes, 1.20 mm dia, through the 1.60 mm lid
  notch minus_x_connectors in lid rim, removed 39.7 mm3
  cut header_2x40    in lid, removed 1006.7 mm3
  cut header_1x02    in lid, removed 39.9 mm3
  cut header_1x01a   in lid, removed 23.7 mm3
  cut header_1x01b   in lid, removed 23.7 mm3
  cut button_lo      in lid, removed 46.1 mm3
  cut button_hi      in lid, removed 46.1 mm3
  added 9 snap beads, 0.45 mm proud (0.25 mm engagement past the wall)
  text 'Cerelog' X -14.84..7.84  Y 0.30..6.20  (0.80 deep, 0.80 left under it)
  text 'ESP-EEG 16CH' X -25.88..18.88  Y -6.20..-1.54  (0.80 deep, 0.80 left under it)
  label 'ON' X -51.30..-46.70  Y -22.44..-19.96  (0.50 deep, 1.10 left under it)
  label 'OFF' X -37.70..-31.30  Y -22.44..-19.96  (0.50 deep, 1.10 left under it)
  label 'microSD' X -29.32..-12.58  Y -22.75..-19.65  (0.50 deep, 1.10 left under it)
base: solids=1 valid=True volume=11259.8
      bbox 120.30 x 50.67 x 10.05  (Z 0.00..10.05)
lid: solids=1 valid=True volume=9139.9
      bbox 120.30 x 50.67 x 5.84  (Z 5.81..11.65)
wrote /Users/simon/Desktop/ESP-EEG-KICAD/3D-print-Case/case for 16CH/stl/case_16ch_base.stl  (25996 facets)
wrote /Users/simon/Desktop/ESP-EEG-KICAD/3D-print-Case/case for 16CH/stl/case_16ch_lid.stl  (41208 facets)
wrote case_16ch.FCStd
wrote case_16ch_params.json
OK

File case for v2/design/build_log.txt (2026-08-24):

=== Cerelog ESP-EEG V2 case ===
outer     102.60 x 46.55 x 9.75 (base+lid = 11.35)
cavity    99.40 x 43.35, corner R 3.30
PCB sits at Z 3.70 .. 5.21
base shell volume 9603.4
after 4 peg standoffs (boss 2.50 + peg 2.71), volume 9795.1
  cut usb_c          on -X wall, removed 160.1 mm3
  cut battery_cable  on -X wall, removed 96.4 mm3
  cut slide_switch   on -Y wall, removed 78.5 mm3
  cut microsd        on -Y wall, removed 100.2 mm3
  cut 6 snap grooves, 0.55 mm deep into the 1.60 mm wall
  thin switch_thin   on -Y wall to 0.60 mm, removed 38.5 mm3
  thin microsd_thin  on -Y wall to 0.80 mm, removed 53.3 mm3
  thin minus_x_ports on -X wall to 0.70 mm, removed 56.8 mm3
lid blank volume 8004.4
  4 lid sleeves: 4.44 tall, bore 2.30 x 1.70 deep, stop 0.10 above PCB
  3 LED holes, 1.20 mm dia, through the 1.60 mm lid
  notch minus_x_connectors in lid rim, removed 40.6 mm3
  cut header_block   in lid, removed 1113.6 mm3
  cut header_block_ext in lid, removed 226.7 mm3
  cut button_lo      in lid, removed 41.9 mm3
  cut button_hi      in lid, removed 42.0 mm3
  cut header_1x02    in lid, removed 37.3 mm3
  added 6 snap beads, 0.45 mm proud (0.25 mm engagement past the wall)
  text 'Cerelog' width 35.28 at y 1.50
  text 'ESP-EEG V2' width 56.85 at y -8.50
  label 'ON' 5.76 wide at (-38.00, -18.80), 0.50 deep
  label 'OFF' 7.99 wide at (-27.00, -18.80), 0.50 deep
  label 'microSD' 16.75 wide at (-12.10, -18.80), 0.50 deep
base: solids=1 valid=True volume=9172.7
      bbox 102.60 x 46.55 x 9.75  (Z 0.00..9.75)
lid: solids=1 valid=True volume=6500.6
      bbox 102.60 x 46.55 x 6.04  (Z 5.31..11.35)
wrote /Users/simon/Desktop/ESP-EEG-KICAD/3D-print-Case/case for v2/stl/case_v2_base.stl  (7810 facets)
wrote /Users/simon/Desktop/ESP-EEG-KICAD/3D-print-Case/case for v2/stl/case_v2_lid.stl  (34332 facets)
wrote case_v2.FCStd
wrote case_v2_params.json
OK

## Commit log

2026-02-17 new repo
    [Case.FCStd]
2026-02-17 photo preview
    [Case-Body.stl, Case-Lid.stl, Case.stl]
2026-02-17 updated lid
    [Case-Lid_v1,2.stl, case_lid.stl]
2026-02-17 better base
    [Case-Body.stl, better_base.FCStd, case_base_fixed.stl]
2026-08-24 added case for v2
    [Case.FCStd, assembly_v2.FCStd, case_v2.FCStd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]
2026-08-30 updated description
    [Case.FCStd, Optional_locking_base.stl, better_base.FCStd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]
2026-09-02 case update
    [assembly_16ch.FCStd, case_16ch.FCStd, case_16ch_base.stl]
2026-09-02 README: stack both 16CH previews in the 16CH column
    The photo composite and the CAD render now sit in the same table cell,
    one above the other, so the 16CH column carries both and the v2/16CH
    side-by-side comparison stays intact.
    Claude-Session: https://claude.ai/code/session_01PaZABrfo1u7u2UmgLw54Ee
